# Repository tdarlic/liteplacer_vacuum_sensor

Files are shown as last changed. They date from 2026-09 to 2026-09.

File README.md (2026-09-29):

# LitePlacer Vacuum Sensor

Small analog vacuum-sensor board for a pick-and-place machine (LitePlacer-style, Smoothieboard v1.1 + OpenPnP 2.6).
It measures the vacuum at the nozzle so OpenPnP can check that a part was picked (*Part On*) and released (*Part Off*).

- **Sensor:** NXP/Freescale **MPXV6115VC6U** (−115…0 kPa, 5 V, ratiometric)
- **Buffer:** Microchip **MCP6001UT-I/OT** rail-to-rail op-amp powered from the Smoothie's 3.3 V, so the output can never exceed the ADC range
- **Output:** 0.2…3.05 V into a Smoothieboard thermistor input (P0.23 / T0), read with `M105`
- **Board:** 56 × 20 mm, 2 layers, 1.6 mm, M5 hole to mount it at the nozzle holder, 2 × M3 holes

Full design notes, calculations, bring-up, Smoothieware and OpenPnP configuration are in
[`vacuum-sensor.md`](vacuum-sensor.md).

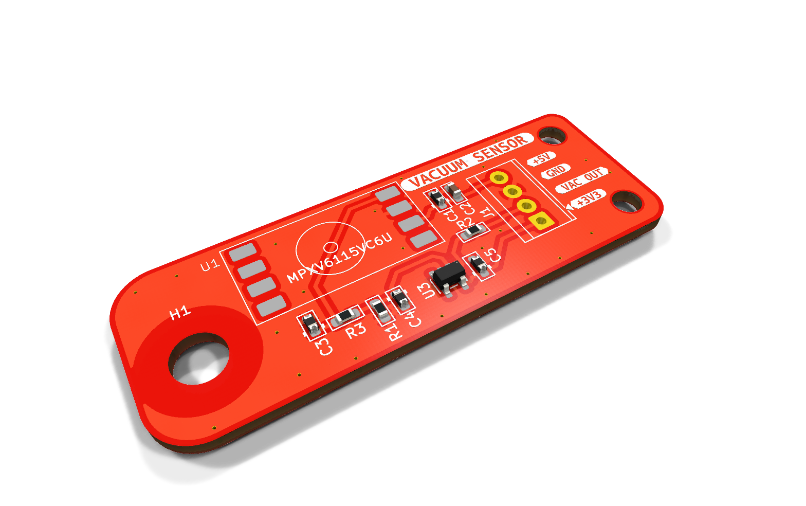
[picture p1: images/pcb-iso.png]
PCB 3D render


## PCB

| Top | Bottom |
|---|---|
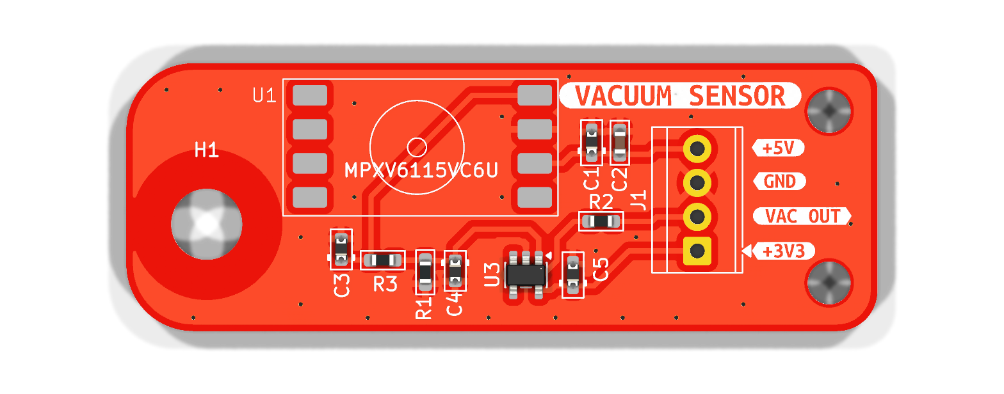
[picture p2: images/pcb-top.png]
PCB top
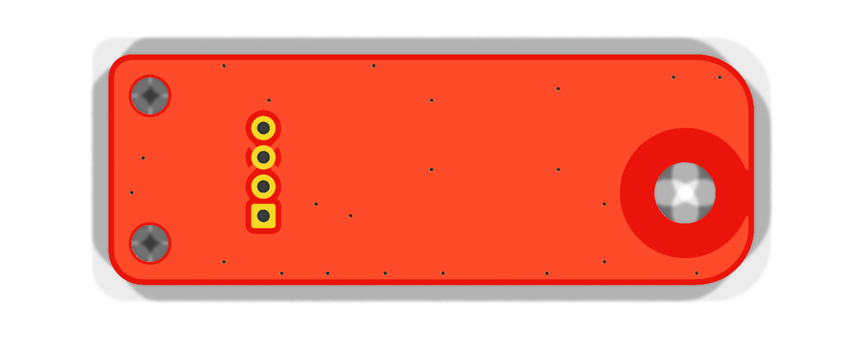
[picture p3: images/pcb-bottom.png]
PCB bottom
|  |  |

> The 3D renders show only the footprint pads for U1 (sensor) and J1 (terminal block), because those parts have no 3D model in the project.

## Schematic

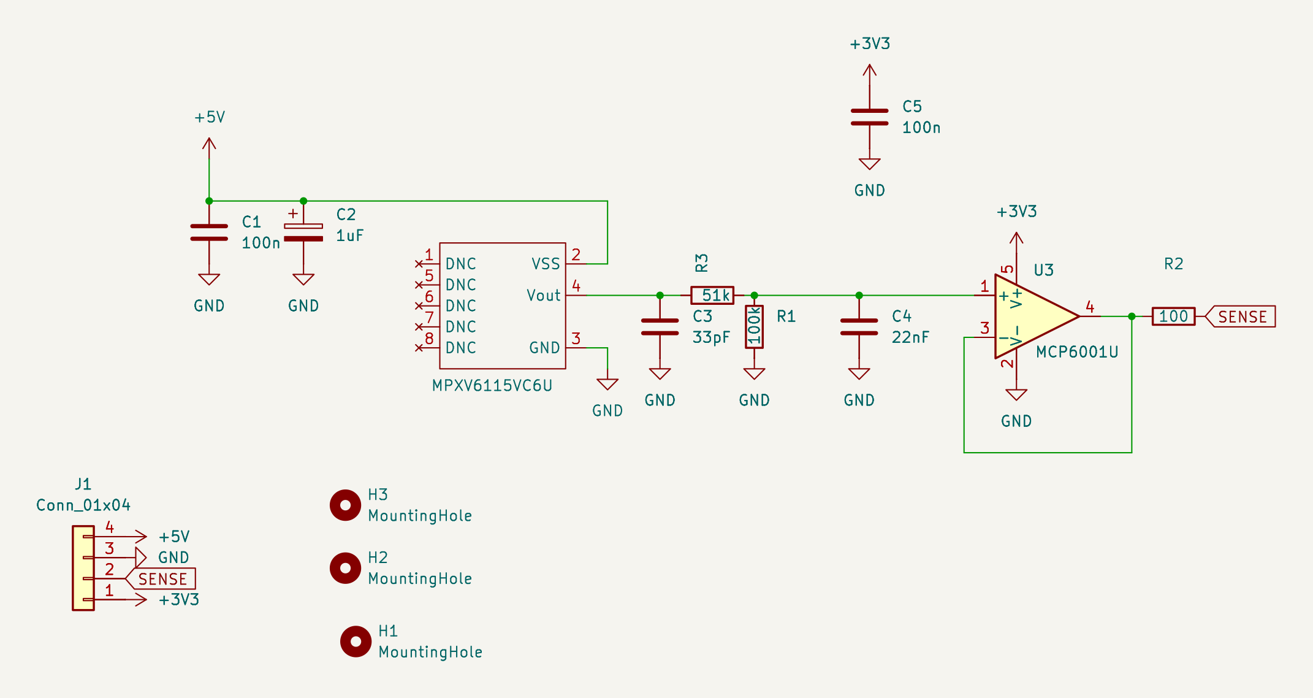
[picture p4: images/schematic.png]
Schematic


Also available as [SVG](images/schematic.svg) and [PDF](images/schematic.pdf).

### How it works

```
MPXV6115V (5 V)  ──  R3 51k / R1 100k divider (×0.662)  ──  MCP6001U follower (3.3 V)  ──  R2 100 Ω  ──  Smoothie P0.23
4.6 V at atmosphere      + C3 33 pF, C4 22 nF (~210 Hz low-pass)                                          (T0 thermistor input)
0.2 V at full vacuum
```

- The sensor output reaches 4.6 V (up to ~4.8 V worst case), so the divider brings it down to ~3.05 V.
- The follower drives the Smoothie input with low impedance, so the board's 4.7 kΩ thermistor pull-up doesn't load the divider.
- Because the op-amp runs from the Smoothie's own 3.3 V, the ADC pin can't be over-driven.
- R2 isolates the op-amp output from the capacitance on the Smoothie input (prevents oscillation).

**Lower reading = more vacuum.**

## Connector J1

| Pin | Signal | Smoothieboard v1.1 |
|---|---|---|
| 1 (square) | +3V3 | 3.3 V pin of the VBB / 3.3V / GND connector |
| 2 | VAC OUT (SENSE) | P0.23 – T0 thermistor input, signal pin |
| 3 | GND | GND on the serial debug header |
| 4 | +5V | 5 V on the serial debug header |

> ⚠ The Smoothie's VBB / 3.3V / GND connector also carries **VBB (12–24 V motor supply)**. A wire on the wrong
> pin destroys the op-amp and probably the LPC1769. Check with a meter before powering up.

## Bill of materials

| Ref | Value | Package | Note |
|---|---|---|---|
| U1 | MPXV6115VC6U | SOP-8 (side port) | Pins 1, 5–8 must stay unconnected |
| U3 | MCP6001UT-I/OT | SOT-23-5 | Must be the **U** pinout (1 = VIN+, 4 = VOUT) |
| R3 | 51 kΩ 1 % | 0603 | Divider top |
| R1 | 100 kΩ 1 % | 0603 | Divider bottom |
| R2 | 100 Ω | 0603 | Output isolation resistor |
| C1 | 100 nF | 0603 | Sensor supply decoupling |
| C2 | 1 µF | 0603 | Sensor supply bulk |
| C3 | 33 pF | 0603 | Sensor output filter |
| C4 | 22 nF | 0603 | Low-pass with the divider (fc ≈ 210 Hz); 47 nF for ≈ 100 Hz |
| C5 | 100 nF | 0603 | Op-amp bypass |
| J1 | 4-pin terminal block, 2.54 mm | TE 282834-4 | |

> Reference designators here follow the KiCad design. `vacuum-sensor.md` uses the numbering from the original
> hand-wired prototype (there R1 = 51k, R2 = 100k, R3 = 100 Ω).

## Expected output

Sensor supply 5.0 V, reading from Smoothieware `ad8495` channel (`reading = V / 0.005`):

| Vacuum | Sensor out | Op-amp out | At Smoothie pin* | `V:` reading |
|---|---|---|---|---|
| 0 kPa (atmosphere) | 4.60 V | 3.05 V | 3.05 V | ≈ 610 (measured 614) |
| −40 kPa | 3.07 V | 2.03 V | 2.06 V | ≈ 410 |
| −60 kPa | 2.30 V | 1.53 V | 1.56 V | ≈ 310 |
| −80 kPa | 1.54 V | 1.02 V | 1.07 V | ≈ 215 |
| −115 kPa (full) | 0.20 V | 0.13 V | 0.20 V | ≈ 40 |

\* The Smoothie's 4.7 kΩ pull-up and R2 add a small linear offset; OpenPnP only compares readings, so it doesn't matter.

## Firmware and OpenPnP (short version)

Smoothieware `config`:

```
temperature_control.vacuum.enable          true
temperature_control.vacuum.sensor          ad8495
temperature_control.vacuum.ad8495_pin      0.23
temperature_control.vacuum.ad8495_offset   0
temperature_control.vacuum.designator      V
temperature_control.vacuum.heater_pin      nc
temperature_control.vacuum.max_temp        1000      # must be above 660, or Smoothie HALTs
```

OpenPnP actuator (Double): read command `M105`, read regex `.*V:(?<Value>-?\d+\.?\d*).*`,
set as the nozzle's *Vacuum Sense Actuator*.

The air line needs a **restriction** between the constantly running pump and the nozzle/sensor tee, otherwise the
reading is the same with the tip open or blocked. See §8b of [`vacuum-sensor.md`](vacuum-sensor.md) for measured
values and starting part-detection thresholds.

## Files

| File | Content |
|---|---|
| `liteplacer_vacuum_sensor.kicad_pro/.kicad_sch/.kicad_pcb` | KiCad project (KiCad 10) |
| `vacuum-sensor.md` | Full design and integration notes |
| `images/` | Renders and schematic exports |
| `1735222.pdf` | MPXV6115V datasheet (Freescale) |
| `DS_mpxv6115v6.pdf` | MPXV6115V6 datasheet (ST, second source) |

### Regenerating the images

```sh
kicad-cli pcb render -o images/pcb-top.png    --side top    --width 1600 --height 640 --quality high --zoom 1.9 liteplacer_vacuum_sensor.kicad_pcb
kicad-cli pcb render -o images/pcb-bottom.png --side bottom --width 1600 --height 640 --quality high --zoom 1.9 liteplacer_vacuum_sensor.kicad_pcb
kicad-cli pcb render -o images/pcb-iso.png    --side top --rotate '-40,0,30' --perspective --width 1600 --height 1000 --quality high --zoom 1.1 liteplacer_vacuum_sensor.kicad_pcb
kicad-cli sch export svg -o images --exclude-drawing-sheet liteplacer_vacuum_sensor.kicad_sch && mv images/liteplacer_vacuum_sensor.svg images/schematic.svg
kicad-cli sch export pdf -o images/schematic.pdf liteplacer_vacuum_sensor.kicad_sch
```

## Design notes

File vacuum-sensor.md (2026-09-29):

# Vacuum sensing – MPXV6115VC6U + MCP6001UT-I/OT → Smoothieboard v1.1 → OpenPnP 2.6

Reference notes for adding analog vacuum sensing to the pick-and-place machine.

**Final parts:** NXP/Freescale **MPXV6115VC6U** vacuum sensor + Microchip **MCP6001UT-I/OT** op-amp.

> **Checked against datasheets:** MCP6001U pinout, supply/input/output ranges and bypass advice
> (Microchip DS20001733L); MPXV6115V pinout, transfer function, output current and application
> circuit (Freescale MPXV6115V Rev 3).
> Smoothieware `ad8495` options checked against <https://smoothieware.org/temperaturecontrol>.
> **Tested on the machine (2026-09-29):** signal on P0.23 (T0) with the config in §7, `heater_pin nc`
> sensor-only channel, readings in OpenPnP via `M105`.

---

## 1. Concept

```
pump ── restriction ──┬── nozzle
                      ├── vent valve (to outside air)
                      └── tee
                           │
     MPXV6115V   (5 V supply, 4.6 V at atmosphere → 0.2 V at full vacuum)
           │
     divider 51k / 100k  (× 0.662)  + RC low-pass
           │
     MCP6001U voltage follower  (3.3 V supply, rail-to-rail)
           │
     100 Ω → Smoothieboard thermistor input (LPC1769 ADC, 0–3.3 V)
           │
     Smoothieware temperature_control (ad8495 = linear)  →  M105  →  OpenPnP actuator
```

Why this way:

| Problem | Solution |
|---|---|
| Sensor output reaches **4.6 V** (up to ~4.8 V worst case), ADC max is **3.3 V** | Divider 51k/100k → 3.05 V nominal, 3.20 V at worst-case Vs = 5.25 V |
| Thermistor inputs have a **4.7 kΩ pull-up to 3.3 V** on the board, which would load a plain divider | Op-amp follower drives the pin with low impedance |
| Must never put > 3.3 V on the ADC | MCP6001U is powered from the **Smoothie 3.3 V**, so its output **physically can't exceed 3.3 V** |
| Must use as much ADC range as possible | MCP6001U inputs and outputs reach both supply rails (input VSS−0.3 … VDD+0.3 V, output within 25 mV of the rails), so the signal can go up to ~3.05 V |
| Sensor output current is limited (0.5 mA max) | Divider draws only ≈ 30 µA (151 kΩ total). The datasheet's own example load is 51 kΩ |
| Noise from the pump and steppers | 33 pF on sensor output + RC low-pass (≈ 210 Hz) + op-amp bypass caps |
| Op-amp driving the capacitor on the Smoothie input could oscillate | 100 Ω series resistor (R_ISO, datasheet §4.3) |

---

## 2. Schematic

```
 +5V (Smoothie serial debug header – see §6)
  │
  ├──────────┬──────────────┐
  │          │              │
  │       C1 100nF       C2 1.5µF (optional, bulk)
  │          │              │
  │         GND            GND
  │
  │   ┌───────────────┐
  └───┤ 2  Vs         │
      │               │
      │  MPXV6115VC6U │ 4  Vout
      │  (U1)         ├──────┬────── R1 51k ─────┬────────────────┐
      │               │      │                  │                │
      │ 3  GND        │   C3 33pF           R2 100k    C4 22nF   │
      └──────┬────────┘      │                  │         │      │
             │              GND                GND       GND     │
            GND                                                  │
   (pins 1, 5, 6, 7, 8: leave unconnected)                       │
                                                                 │
                                                                 │
 +3.3V (Smoothie) ──┬──────────────── 5  VDD                     │
                    │                                            │
                 C5 100nF          ┌─ 1  VIN+ ◄──────────────────┘
                 (≤ 2 mm from      │
                  pin 5)           │    MCP6001UT-I/OT  (U2, SOT-23-5)
                    │              │
                   GND        ┌─── 3  VIN−
                              │
                              │    4  VOUT ──┬── R3 100Ω ────► Smoothie P0.23
                              │              │                  (T0 thermistor input, signal pin)
                              └──────────────┘
                                   2  VSS ── GND ────────────► Smoothie GND
                                                                (serial debug header)
```

The MCP6001U is wired as a **voltage follower**: output connected straight to VIN−, gain = 1.
Put a 1 µF or larger capacitor on the 3.3 V supply within ~10 cm (datasheet §4.4). The Smoothieboard's own
3.3 V decoupling normally covers this if the wires are short.

### Pinouts (verified against datasheets)

**MPXV6115VC6U (SOP-8, pin 1 marked by notch / identifier)**

| Pin | Function |
|---|---|
| 2 | Vs (+5 V, 4.75–5.25 V) |
| 3 | GND |
| 4 | Vout |
| 1, 5, 6, 7, 8 | Internal / no connect – **leave unconnected** (not even to GND) |

**MCP6001UT-I/OT (SOT-23-5) – "U" variant!**

| Pin | Function |
|---|---|
| 1 | VIN+ |
| 2 | VSS (GND) |
| 3 | VIN− |
| 4 | VOUT |
| 5 | VDD (+3.3 V) |

> ⚠ The plain **MCP6001** (1 = VOUT, 2 = VSS, 3 = VIN+, 4 = VIN−, 5 = VDD) and the **MCP6001R**
> (1 = VOUT, 2 = VDD, 3 = VIN+, 4 = VIN−, 5 = VSS) have **different pinouts** in the same package.
> Make sure the reel/marking really is the **U** version. The U pinout matches the LM321 and LMV321.

---

## 3. Bill of materials

| Ref | Value | Note |
|---|---|---|
| U1 | MPXV6115VC6U | Vacuum sensor, −115…0 kPa, 5 V, ratiometric |
| U2 | MCP6001UT-I/OT | Single op-amp, rail-to-rail input and output, 1.8–6 V, SOT-23-5 |
| R1 | 51 kΩ 1 % | Divider top |
| R2 | 100 kΩ 1 % | Divider bottom |
| R3 | 100 Ω | Output isolation (R_ISO) |
| C1 | 100 nF ceramic | Sensor supply decoupling (datasheet application circuit) |
| C2 | 1.5 µF ceramic | Extra bulk on the sensor supply |
| C3 | 33 pF ceramic | Sensor output filter (datasheet application circuit shows 47 pF; 33 pF works the same here) |
| C4 | 22 nF ceramic | RC low-pass with the divider: R_th = 33.8 kΩ → fc ≈ 210 Hz, τ ≈ 0.75 ms |
| C5 | 100 nF ceramic | MCP6001 bypass, within 2 mm of pin 5 |

Supply currents: sensor 6 mA typ / 10 mA max from 5 V; op-amp ≈ 100 µA from 3.3 V.

Optional: if you want a slower, quieter signal, raise C4 to 47 nF (≈ 100 Hz). A pick takes tens of
milliseconds, so either value is fast enough.

---

## 4. Expected voltages

Sensor transfer function (datasheet): `Vout = Vs × (0.007652 × P + 0.92)`, P in kPa (−115 … 0).
With Vs = 5.0 V and the 51k/100k divider (× 0.6623):

| Vacuum (kPa) | Sensor Vout | Divider = op-amp out | Approx. at Smoothie pin* |
|---|---|---|---|
| 0 (atmosphere) | 4.60 V | 3.05 V | 3.05 V |
| −20 | 3.83 V | 2.54 V | 2.56 V |
| −40 | 3.07 V | 2.03 V | 2.06 V |
| −60 | 2.30 V | 1.53 V | 1.56 V |
| −80 | 1.54 V | 1.02 V | 1.07 V |
| −100 | 0.77 V | 0.51 V | 0.57 V |
| −115 (full) | 0.20 V | 0.13 V | 0.20 V |

\* The 4.7 kΩ on-board pull-up and R3 add a small **linear** offset
(`Vpin ≈ Vop + (3.3 − Vop) × 0.021`). That doesn't matter, because OpenPnP only compares readings.

Worst case: Vs = 5.25 V gives 4.83 V from the sensor → 3.20 V after the divider, still under 3.3 V. If the sensor
saturates higher still, the op-amp output stops at its 3.3 V supply anyway.

**Lower reading = more vacuum.** A typical PnP pump gives roughly −40 … −80 kPa at a sealed nozzle,
which is about 2.1 … 1.1 V at the pin: a swing of about 1 V (≈ 1200 ADC counts).

The sensor is **ratiometric**: its output scales with the 5 V supply. The ADC measures against 3.3 V, so any
drift in the 5 V supply shows up as drift in the reading. Use a stable 5 V (§6).

---

## 5. Build and bench test (before connecting to Smoothie)

1. Check the MCP6001 marking/reel is the **U** version and that the pins are soldered as in §2.
2. Power from a bench supply: 5 V to the sensor, 3.3 V to the op-amp, common GND. **Nothing connected to the Smoothie yet.**
3. Measure sensor pin 4: ≈ 4.6 V at atmosphere.
4. Measure U2 pin 1 (VIN+): ≈ 3.05 V.
5. Measure U2 pin 4 (VOUT): same as pin 1, within a few mV.
6. Suck on the tube or connect the pump. All three voltages should drop smoothly (see the table in §4).
7. Only connect to the Smoothieboard when VOUT is confirmed **≤ 3.3 V** and follows the input.

---

## 6. Wiring to the Smoothieboard

### As built

| Signal | Wire colors (doubled) | Where on the Smoothieboard v1.1 | Notes |
|---|---|---|---|
| **Vacuum signal** (U2 VOUT via R3) | green + yellow | **P0.23** – T0 thermistor input, signal pin | `ad8495_pin 0.23` in §7 |
| **+5 V** (sensor) | red + pink | **Serial debug header** – 5 V pin | |
| **GND** (whole board) | grey + blue | **Serial debug header** – GND pin | One common ground for sensor and op-amp |
| **+3.3 V** (op-amp) | brown + white | **VBB / 3.3V / GND connector** in the middle of the board – 3.3 V pin | Same 3.3 V the ADC measures against, so the op-amp output can't exceed it |

> ⚠ **The VBB / 3.3V / GND connector also carries VBB, the main supply (motor voltage, typically 12–24 V).**
> A wire on the wrong pin, or a connector plugged in the wrong way round, puts VBB straight into the MCP6001, and
> through its output into P0.23. That would destroy the op-amp and probably the LPC1769. Label the wires and
> check with a meter before powering up after any rework.
> Only the **brown + white** wires go to this connector, on its **3.3 V** pin.

Other thermistor inputs, if P0.23 is ever needed for something else:

| Connector | ADC pin (Smoothie config name) |
|---|---|
| T0 | `0.23` (used) |
| T1 | `0.24` |
| T2 | `0.25` |
| T3 | `0.26` |

### Notes

- **Ground:** one common ground. Don't split the 5 V and 3.3 V grounds; on the Smoothieboard they're the same
  ground plane. Using the GND pin of the VBB/3.3V/GND connector as well is fine. What matters is keeping pump,
  valve and motor return currents off the sensor's ground wire.
- **5 V:** the sensor is ratiometric, so a drifting 5 V shows up as a drifting reading. The serial header's 5 V is
  the Smoothie's 5 V rail. If that rail is fed only from USB, the reading shifts slightly when the USB supply changes.
  The on-board 5 V regulator (or an external 5 V supply) is more stable.
- **Power-up order:** if the sensor's 5 V ever comes from a separate supply, it could be live while the
  Smoothie's 3.3 V is off. R1 limits the current into the op-amp input to about 0.1 mA, well within its 2 mA rating.
- **Cable:** 8-core cable, each connection on two wires joined at both ends:
  red/pink = +5 V, grey/blue = GND, brown/white = +3.3 V, green/yellow = signal.
  If the cable is shielded, connect the shield at the Smoothie end only.

### Air line

The pump **runs constantly.** The valve is a **vent valve**: it opens the line to outside air to release the part.
The sensor tees into the line about 10 cm from the nozzle holder. Pump, sensor, vent and nozzle all share one line,
so it doesn't matter which side of the valve the sensor is on. What matters is the **restriction** between the pump
and the line (see §8b).

---

## 7. Smoothieware configuration

Add a "temperature" channel that reads the voltage linearly. It uses the `ad8495` sensor type, which is documented
on <https://smoothieware.org/temperaturecontrol> under *AD8495 Thermocouple Amplifier*. The examples higher up
that page (`thermistor_pin`, `beta`, `coefficients`, `rt_curve`) are for the default **thermistor** sensor type
and aren't used here.

```
temperature_control.vacuum.enable          true
temperature_control.vacuum.sensor          ad8495
temperature_control.vacuum.ad8495_pin      0.23      # ADC pin of the thermistor input used (T0)
temperature_control.vacuum.ad8495_offset   0
temperature_control.vacuum.designator      V
temperature_control.vacuum.heater_pin      nc
temperature_control.vacuum.max_temp        1000      # MUST be above 660 – see below
```

### How the reading scales

Per the Smoothieware docs: `reading = V / 0.005 − ad8495_offset`. With offset 0, **1 V reads as 200**, and the
full 0–3.3 V ADC range maps to 0–660.

| Condition | Voltage at pin | `V:` reading |
|---|---|---|
| Atmosphere | ≈ 3.05 V | ≈ 610 (measured: 614) |
| Suck by mouth (bench test, ≈ −37 kPa) | ≈ 2.10 V | ≈ 420 |
| Pump, sealed nozzle (−60 … −80 kPa) | ≈ 1.56 … 1.07 V | ≈ 313 … 213 |

Then `M105` returns something like `ok T:... V:612.3 /0.0 @0`.

### Notes

- **`max_temp` is essential.** The docs say that exceeding `max_temp` turns off all heaters and puts Smoothie into
  **HALT** (clear with `M999` / reset). The atmospheric reading (≈ 612) is above a typical hotend limit, so set
  `max_temp` above the largest possible reading (660).
- **`heater_pin nc`:** "nc" is Smoothie's usual value for "not connected". The docs page doesn't describe using a
  channel as a sensor only, so on the first boot check that `M105` shows `V:` and nothing halts.
- **Pin 0.23 is the default hotend thermistor pin.** Remove or disable (`enable false`) the existing
  `temperature_control.hotend` section, and any other section that uses `0.23`.
- **Fallback** if your firmware build has no `ad8495` type: use the default thermistor sensor type. The reading
  is then not linear, but it still changes steadily in one direction with vacuum, and OpenPnP thresholds still work.

Test from the OpenPnP console (or a terminal): `M105` with the pump off, then with the pump on and the nozzle
blocked. The `V:` value must change clearly.

---

## 8. OpenPnP 2.6 configuration

1. **Machine Setup → Actuators →** use the existing `AVACS` actuator (or add one, e.g. `VAC_SENSE`)
   - Driver: the GcodeDriver
   - Value type: **Double**
   - `ACTUATOR_READ_COMMAND`: `M105`
   - `ACTUATOR_READ_REGEX`: `.*V:(?<Value>-?\d+\.?\d*).*`
   - Test with the **Read** button in the actuator panel.
2. **Nozzle** → set the *Vacuum Sense Actuator* to `AVACS`, and the vacuum actuator to the valve (`AVAC`).
   On this machine both were already set.
3. **Nozzle tip → Vacuum tab** (for each tip):
   - Take readings with the vacuum **off**, the vacuum **on and no part**, and a **part picked**.
   - Turn on the **Part On** check. The threshold goes between the "no part" and "part picked" readings.
   - Turn on the **Part Off** check. The threshold goes between the "part picked" and "no part" readings.
   - Try the *Establish Level* / *Difference* methods if a plain threshold isn't reliable
     (small parts on big tips give only small differences).
4. Run a few picks and discards and check the log to see whether the part detection fires correctly.

Always **close OpenPnP and back up `~/.openpnp2`** before editing `machine.xml` by hand.

---

## 8b. As built – air line and measured values (2026-09-29)

### Air-line layout

The pump runs constantly. The valve (AVAC) is a **vent valve**: it opens the line to outside air to drop the part.

```
pump ── restriction (short section of thinner tube) ──┬── sensor (≈ 10 cm from the nozzle holder)
                                                      ├── vent valve (AVAC)
                                                      └── nozzle
```

**The restriction is essential.** Without it the pump holds the whole line at full vacuum whether the tip is
open or blocked, so part detection can't work (measured before the restriction: 380–420 in every state).
It acts like an air version of a voltage divider. With the tip blocked, the line still reaches full pump vacuum.
With the tip open, air leaks in through the tip faster than the restriction lets it out, so the reading rises
towards atmosphere.

- Too little difference between open and blocked → use a narrower or longer restriction.
- Vacuum takes too long to build → use a wider or shorter restriction.

### Measured readings (smallest nozzle tip, `V:` value from `M105`)

| State | Reading |
|---|---|
| Vacuum off (vent open) | ≈ 614 |
| Vacuum on, tip empty | ≈ 500 |
| Vacuum on, part on tip | ≈ 380–400 |

### OpenPnP config applied

- Actuator **AVACS** (id `A1`): value type Double, driver GcodeDriver, read command `M105`,
  read regex `.*V:(?<Value>-?\d+\.?\d*).*`
- Nozzle **N**: vacuum sense actuator = AVACS, vacuum actuator = AVAC (already set).
- Backup of the config before this change: `~/.openpnp2/machine.xml.before-vacsense`

### Starting part-detection values (smallest tip, set in the GUI)

| Setting | Value | Why |
|---|---|---|
| Part On method | Absolute | |
| Part On low / high | 0 / 450 | halfway between part-held (≈ 400) and empty (≈ 500) |
| Pick dwell | ≈ 200 ms | vacuum must settle before the check; replace with the measured settling time |
| Part Off method | Absolute | |
| Part Off low / high | 450 / 560 | empty ≈ 500 passes. Part still stuck (< 450) fails. No vacuum (≈ 614) fails |
| Part-off probing time | ≈ 200 ms | vacuum is applied briefly for the check |

Every nozzle tip needs its own values. Larger tips read closer to 614 when empty, so the gap gets bigger.
If the reading jumps by more than about ±15 while nothing changes, widen the margins or increase C4 to 47 nF.

---

## 9. Troubleshooting

| Symptom | Likely cause |
|---|---|
| VOUT doesn't follow VIN+ | Wrong MCP6001 variant (plain or R instead of U), or VIN− not tied to VOUT |
| Machine HALTs after boot | `max_temp` missing or below 660 in the `vacuum` section |
| Op-amp output stuck at 3.3 V at atmosphere | Divider not working – R1 (51k) missing or wrong value (happened during the build) |
| Reading doesn't change | Wrong ADC pin in config, sensor pins 1/5–8 connected, sensor 5 V missing |
| Same reading with tip open and blocked | Restriction between pump and line missing or too wide (§8b) |
| Reading stuck at ~3.3 V | Op-amp not powered, or divider R2 missing |
| Reading stuck near 0 V | Sensor 5 V missing, or R1 open |
| Noisy reading | Missing C4/C5, ground taken from a motor connector, unshielded cable next to steppers |
| Reading drifts over time | 5 V supply not stable (USB power), sensor warming up |
| Output oscillates (check with a scope) | R3 missing or shorted |
| Very small difference between "no part" and "part" | Restriction too wide, nozzle tip hole too big for the part, leaks in tubing |
| Vacuum builds too slowly / weak pick | Restriction too narrow, leaks in tubing |
| Op-amp or Smoothie dead after rework | Check the VBB/3.3V/GND connector wiring – VBB on the 3.3 V wire |

---

## 10. References

- Microchip MCP6001/1R/1U/2/4 datasheet (DS20001733L):
  <https://ww1.microchip.com/downloads/en/DeviceDoc/MCP6001-1R-1U-2-4-1-MHz-Low-Power-Op-Amp-DS20001733L.pdf>
- Freescale/NXP MPXV6115V datasheet (Rev 3): <https://docs.rs-online.com/6ca8/0900766b810bd3f3.pdf>
- ST datasheet for MPXV6115V6 / MPXV6115VC6 (second source): <https://www.st.com/resource/en/datasheet/mpxv6115v6.pdf>

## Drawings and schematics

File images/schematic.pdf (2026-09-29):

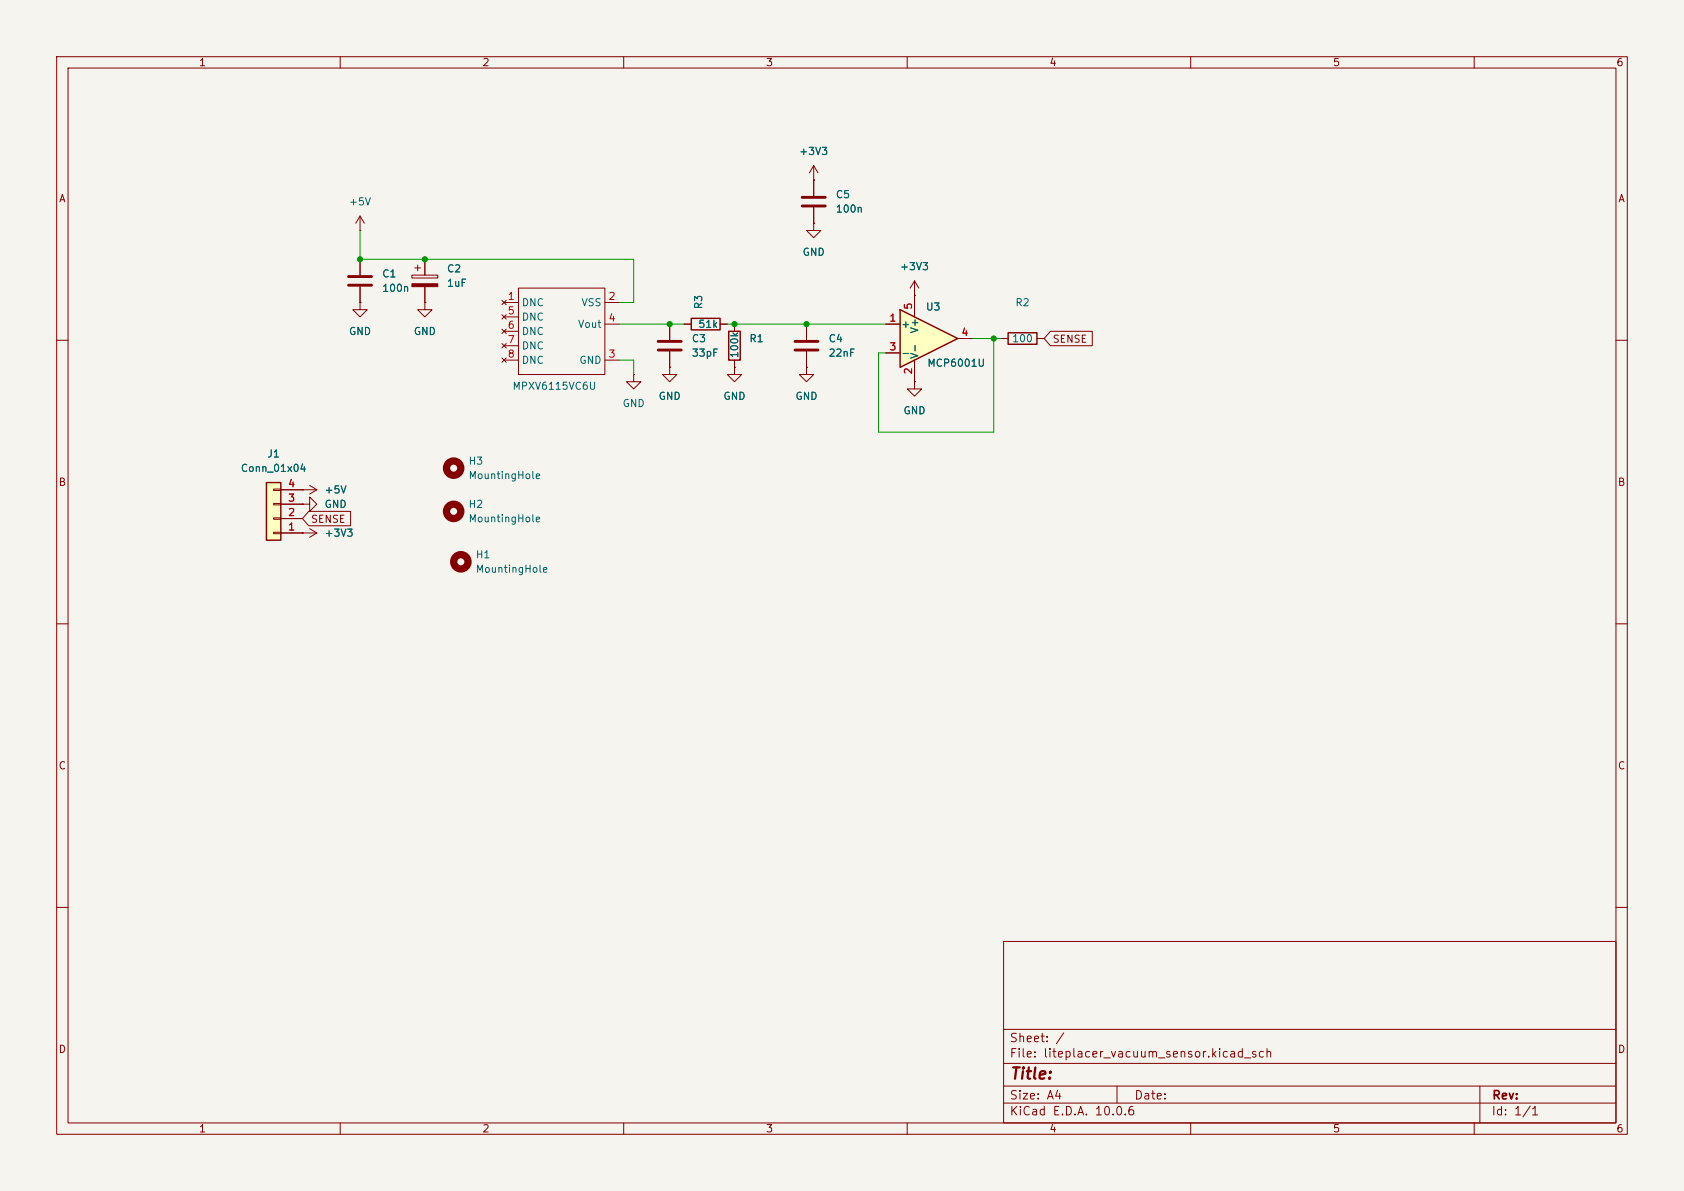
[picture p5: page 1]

Size: A4 | Rev:
KiCad E.D.A. 10.0.6 | Id: 1/1

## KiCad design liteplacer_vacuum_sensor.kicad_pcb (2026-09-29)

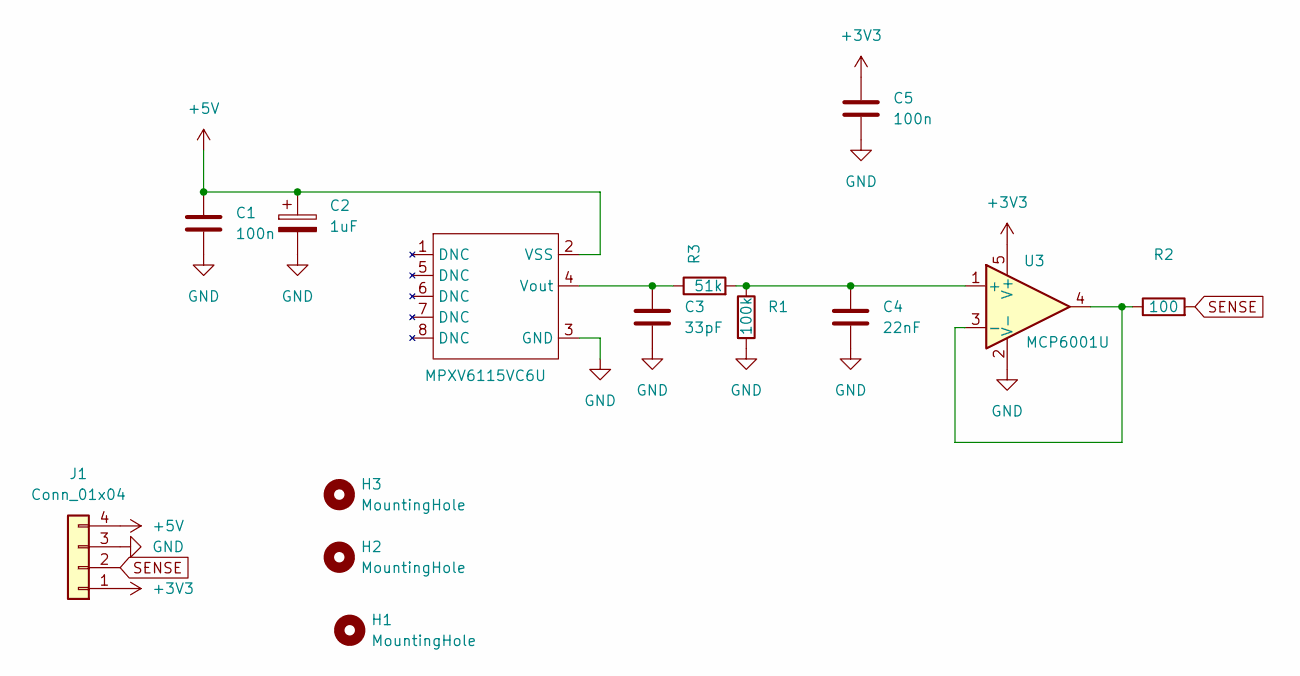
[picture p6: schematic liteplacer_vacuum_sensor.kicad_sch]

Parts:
C1, C5: 100n; D_0603_1608Metric_Castellated
C2: 1uF; C_0603_1608Metric_Pad1.08x0.95mm_HandSolder
C3: 33pF; D_0603_1608Metric
C4: 22nF; D_0603_1608Metric
H1: MountingHole; MountingHole_5.3mm_M5_ISO14580
H2, H3: MountingHole; MountingHole_3.2mm_M3
J1: Conn_01x04; TerminalBlock_TE_282834-4_1x04_P2.54mm_Horizontal
R1: 100k; R_0603_1608Metric_Pad1.05x0.95mm_HandSolder
R2: 100; R_0603_1608Metric_Pad1.05x0.95mm_HandSolder
R3: 51k; R_0603_1608Metric_Pad1.05x0.95mm_HandSolder
U1: MPXV6115VC6U
U3: MCP6001U; SOT-23-5

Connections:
+3V3: C5.1, J1.1, U3.5 (V+)
+5V: C1.1, C2.1, J1.4, U1.2 (VSS)
GND: C1.2, C2.2, C3.2, C4.2, C5.2, J1.3, R1.2, U1.3 (GND), U3.2 (V-)
unnamed: C3.1, R3.1, U1.4 (Vout)
unnamed: C4.1, R1.1, R3.2, U3.1 (+)
unnamed: R2.1, U3.3 (-), U3.4
SENSE: J1.2, R2.2

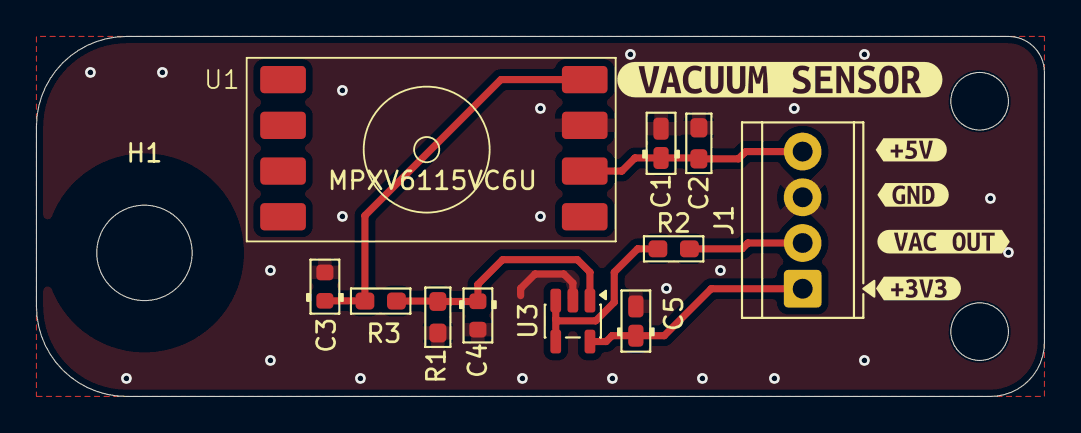
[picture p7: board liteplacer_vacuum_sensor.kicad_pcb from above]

Board: 2 copper layers, 56.0 x 20.0 mm, 19 parts (0 on the bottom side), 7 nets.

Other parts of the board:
kibuzzard-6ABBD2B0: G***; kibuzzard-6ABBD2B0
kibuzzard-6ABBD2C7: G***; kibuzzard-6ABBD2C7
kibuzzard-6ABBD2E9: G***; kibuzzard-6ABBD2E9
kibuzzard-6ABBD49C: G***; kibuzzard-6ABBD49C
kibuzzard-6ABBD306: G***; kibuzzard-6ABBD306

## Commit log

2026-09-29 Adding gerbers
    [liteplacer_vacuum_sensor-B_Cu.gbr, liteplacer_vacuum_sensor-B_Mask.gbr, liteplacer_vacuum_sensor-B_Paste.gbr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]
2026-09-29 Remove gnd referenced mounting hole
    [liteplacer_vacuum_sensor-B_Cu.gbr, liteplacer_vacuum_sensor-B_Mask.gbr, liteplacer_vacuum_sensor-B_Paste.gbr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]
2026-09-29 Fixed the circular keepout area punching a hole in the board
    [liteplacer_vacuum_sensor.kicad_pcb, liteplacer_vacuum_sensor.kicad_sch]
